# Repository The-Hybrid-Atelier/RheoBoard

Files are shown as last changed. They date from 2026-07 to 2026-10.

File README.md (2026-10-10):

# RheoBoard

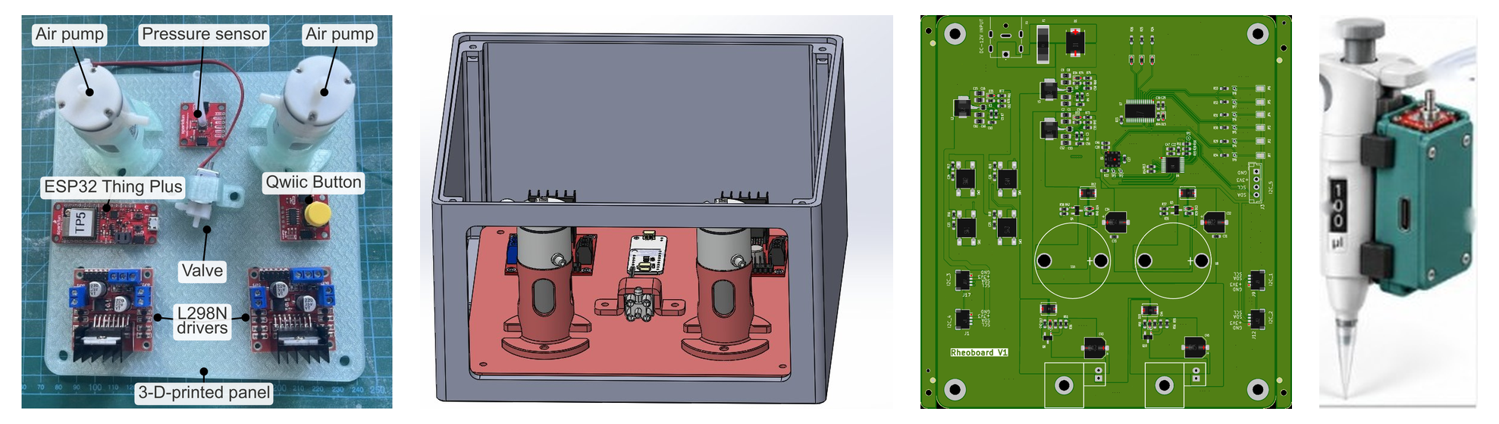
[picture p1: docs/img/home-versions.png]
RheoBoard


RheoBoard is open hardware for pneumatic retraction-extrusion measurements. On command, it runs a REP (retraction-extrusion pulse) and streams the pressure trace.

## Start here

[Wiki Page](https://github.com/The-Hybrid-Atelier/RheoBoard/wiki)

## License

All license notices are consolidated in [`LICENSE`](LICENSE):

- Hardware designs: CERN-OHL-W-2.0
- Firmware: MIT
- Documentation: [CC BY-SA 4.0](https://creativecommons.org/licenses/by-sa/4.0/)

<a href="https://certification.oshwa.org/us002865.html">OSHW certification mark US002865</a>

RheoBoard is certified open source hardware by the Open Source Hardware Association,
UID [US002865](https://certification.oshwa.org/us002865.html); details are on the
[Certification](https://github.com/The-Hybrid-Atelier/RheoBoard/wiki/Certification) page.
The current version is version 1. This is the same version certified by OSHWA as [US002865](https://certification.oshwa.org/us002865.html).
Machine-readable project metadata and the current version are in
[`okh-RheoBoard.yml`](okh-RheoBoard.yml).

## Disclaimer

If you build or distribute a derived unit, do not imply that it is manufactured, sold, warranted,
or endorsed by the original designer.

## Author

Created and maintained by [Charlie Vuong](https://charlie-vuong.com) (The Hybrid Atelier at UT Arlington).

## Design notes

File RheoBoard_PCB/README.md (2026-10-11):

# RheoBoard PCB

This folder holds the PCB designs. There are three versions: [`RheoBoard_v0.05-altium`](RheoBoard_v0.05-altium/), [`RheoBoard_v1`](RheoBoard_v1/), and [`RheoBoard_v1.05`](RheoBoard_v1.05/).

[`RheoBoard_v0.05-altium`](RheoBoard_v0.05-altium/) is a KiCad re-import of the Altium design, saved separately from the other two versions.

[`RheoBoard_v1`](RheoBoard_v1/) holds the KiCad schematic and board for that version, plus symbol, footprint, and 3D libraries, Gerbers, drills, and pick-and-place files.

[`RheoBoard_v1.05`](RheoBoard_v1.05/) holds the v1.05 KiCad project, with revision notes, a BOM, assembly notes, manufacturing files, verification records, and an archive of the historical v1 outputs.

## Files in this folder

Open [`RheoBoard_v1/RheoboardV1/RheoBoard_v1.kicad_pro`](RheoBoard_v1/RheoboardV1/RheoBoard_v1.kicad_pro) in KiCad 10.

- Schematic: [`RheoBoard_v1/RheoboardV1/RheoBoard_v1.kicad_sch`](RheoBoard_v1/RheoboardV1/RheoBoard_v1.kicad_sch)
- Board: [`RheoBoard_v1/RheoboardV1/RheoBoard_v1.kicad_pcb`](RheoBoard_v1/RheoboardV1/RheoBoard_v1.kicad_pcb)
- Libraries: [`RheoBoard_v1/Symbol/`](RheoBoard_v1/Symbol/), [`RheoBoard_v1/Footprint/`](RheoBoard_v1/Footprint/), [`RheoBoard_v1/3D/`](RheoBoard_v1/3D/)
- Gerbers: [`RheoBoard_v1/Gerber/`](RheoBoard_v1/Gerber/)
- Drills: [`RheoBoard_v1/Drill/`](RheoBoard_v1/Drill/)
- Pick-and-place: [`RheoBoard_v1/CPL/CPL.csv`](RheoBoard_v1/CPL/CPL.csv)
- Archived v1 assembly workbook: [`RheoBoard_v1.05/Archive_v1_outputs/BOM/BOM_RheoboardV1_JLCSMT.xlsx`](RheoBoard_v1.05/Archive_v1_outputs/BOM/BOM_RheoboardV1_JLCSMT.xlsx)

License: hardware CERN-OHL-W-2.0 — see [`../LICENSE`](../LICENSE).

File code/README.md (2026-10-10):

# Code

Shared firmware and RheoData notes for the DIY build, the PCB, and the portable version. Install and connect steps are on the [Code](https://github.com/The-Hybrid-Atelier/RheoBoard/wiki/Code) wiki page.

The ESP32 sketch is in `firmware/`. RheoData notes are in `software/`.

Firmware is MIT-licensed. The license notice and full text are in [`../LICENSE`](../LICENSE).

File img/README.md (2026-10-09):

# Images

Project photos and reference photos for the parts in the
[parts list](https://github.com/The-Hybrid-Atelier/RheoBoard/blob/main/BuildYourOwn/hardware/README.md).
One folder per part. Component images come from manufacturer/vendor photography, a freely licensed
source, or a file already in this project, and are for builder identification only.

SparkFun and Adafruit images are used here so a builder can recognize the part when it arrives —
not redistributed as marketing material. Those vendor photos stay under their owners' terms. Link
to the product page for authoritative specs.

| File | Part | Source |
|---|---|---|
| `esp32-thing-plus/esp32-thing-plus.jpg` | SparkFun ESP32 Thing Plus (micro-USB), WRL-15663 | Copied from `BuildYourOwn/images/esp32-thing-plus.jpg`. [SparkFun product page](https://www.sparkfun.com/sparkfun-esp32-thing-plus.html) |
| `qwiic-micropressure/qwiic-micropressure.jpg` | SparkFun Qwiic MicroPressure Sensor, SEN-16476 | Copied from `BuildYourOwn/images/qwiic-micropressure.jpg`. [SparkFun product page](https://www.sparkfun.com/sparkfun-qwiic-micropressure-sensor.html) |
| `qwiic-button/qwiic-button.jpg` | SparkFun Qwiic Button, red, BOB-15932 | Copied from `BuildYourOwn/images/qwiic-button.jpg`. [SparkFun product page](https://www.sparkfun.com/sparkfun-qwiic-button.html) |
| `attiny1616-seesaw/attiny1616-seesaw.jpg` | Adafruit ATtiny1616 Breakout with seesaw, STEMMA QT/Qwiic (PID 5690) | Copied from `BuildYourOwn/images/adafruit-attiny1616-seesaw.jpg`. [Adafruit product page](https://www.adafruit.com/product/5690), image via `https://cdn-shop.adafruit.com/970x728/5690-00.jpg` |
| `air-pump-4699/air-pump-4699.jpg` | Adafruit 4699 — Air Pump and Vacuum DC Motor (ZR370-02PM) | Copied from `BuildYourOwn/images/adafruit-4699-air-pump.jpg`. [Adafruit product page](https://www.adafruit.com/product/4699) |
| `air-valve-4663/air-valve-4663.jpg` | Adafruit 4663 — 6V Air Valve (FA0520E) | Copied from `BuildYourOwn/images/adafruit-4663-air-valve.jpg`. [Adafruit product page](https://www.adafruit.com/product/4663) |
| `l298n/l298n.jpg` | Generic L298N dual H-bridge module | Copied from `BuildYourOwn/images/l298n-motor-driver.jpg`. Cropped from [Wikimedia Commons: *Dosmotorsl298n.jpg*](https://commons.wikimedia.org/wiki/File:Dosmotorsl298n.jpg) by Quel.soler, [CC BY-SA 4.0](https://creativecommons.org/licenses/by-sa/4.0/). No single canonical vendor page exists for this generic module, so this is the best-effort stand-in; swap for your exact board's photo if it differs. |
| `silicone-tube-4661/silicone-tube-4661.jpg` | Adafruit 4661 silicone tubing, 3 mm ID, 5 mm OD, 1 m | Downloaded from [https://cdn-shop.adafruit.com/640x480/4661-00.jpg](https://cdn-shop.adafruit.com/640x480/4661-00.jpg), the product image on [https://www.adafruit.com/product/4661](https://www.adafruit.com/product/4661) |
| `battery-prt-26059/battery-prt-26059.jpg` | SparkFun Lithium Ion Battery 1500 mAh, IEC62133 certified (PRT-26059) | Downloaded from [https://www.sparkfun.com/media/catalog/product/cache/f8158826193ba5faa8b862a9bd1eb9e9/P/R/PRT-26059-Lithium-Ion-Battery-Feature.jpg](https://www.sparkfun.com/media/catalog/product/cache/f8158826193ba5faa8b862a9bd1eb9e9/P/R/PRT-26059-Lithium-Ion-Battery-Feature.jpg), the product image on [https://www.sparkfun.com/lithium-ion-battery-1500mah-iec62133-certified.html](https://www.sparkfun.com/lithium-ion-battery-1500mah-iec62133-certified.html) |
| `panel/panel-annotated.pdf` | Annotated photo of the flat 3D-printed panel | Copied from `BuildYourOwn/cad/encloser/panel-annotated.pdf`. Not fetched. |
| `panel/panel-annotated.jpg` | Same annotated panel photo, as a JPEG | Exported from that one-page PDF (embedded photo, 480×510) so the picture can be shown on a page. Not a new photograph. |
| `panel/encloser_pic1.jpg` | CAD view stored beside the panel print files | Copied from `BuildYourOwn/cad/encloser/encloser_pic1.jpg` and resaved as JPEG. That source file is PNG data with a `.jpg` name. Not fetched. |
| `panel/encloser_pic2.jpg` | CAD view stored beside the panel print files | Copied from `BuildYourOwn/cad/encloser/encloser_pic2.jpg` and resaved as JPEG. That source file is PNG data with a `.jpg` name. Not fetched. |
| `panel/encloser_pic3.jpg` | CAD view stored beside the panel print files | Copied from `BuildYourOwn/cad/encloser/encloser_pic3.jpg` and resaved as JPEG. That source file is PNG data with a `.jpg` name. Not fetched. |
| `teaser/teaser.jpg` | Assembled bench prototype used as the project hero image | Copied from `BuildYourOwn/images/teaser.jpg`. User-provided project photo. |

## Notes

- Originals in `BuildYourOwn/images/` and `BuildYourOwn/cad/encloser/` are left in place.
- If a part is substituted, replace the photo here and update the parts list accordingly.
- No photo is stored here for the GL45 bottle, the GL45 two-port cap, or the tube that connects to
  that cap. Those print files are not in the repository, and no project photo of them was on hand.

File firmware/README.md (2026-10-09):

# Firmware

**Entry point:** [`2P1V_Adafruit/2P1V_Adafruit.ino`](2P1V_Adafruit/2P1V_Adafruit.ino) —
this design's 2 pumps, 1 valve bench firmware for **RheoData** (SparkFun ESP32 Thing Plus,
micro-USB, WRL-15663 + 2× L298N + Qwiic MicroPressure + Qwiic Button + Adafruit ATtiny1616
seesaw breakout). The ESP32 commands the seesaw over Qwiic; seesaw pins `0`, `1`, and `5` then
drive the L298N `ENA`/`ENB` inputs through discrete wires instead of native ESP32 GPIO. The sketch
file/BLE device name in code: `2P1V_Adafruit`.

This firmware is shared by the DIY build, the PCB, and the portable version. Sketch sources live
in `2P1V_Adafruit/` so the sketch folder matches the primary `.ino` filename as Arduino requires.
Firmware is MIT-licensed; the license notice and full text are in the repository-root
[`LICENSE`](../LICENSE). RheoData, the app used with this firmware, is noted in
[`../software/README.md`](../software/README.md). Download, pairing, the connected indicator, and
how to start and name a REP stay TODO and will be specified later in that file and in these notes.

## Toolchain

| Item | Value |
|---|---|
| IDE | [Arduino IDE](https://www.arduino.cc/en/software) 2.x |
| Board | **SparkFun ESP32 Thing Plus** (or generic **ESP32 Dev Module** — plain ESP32-WROOM-32D/E, not S2/S3) |
| ESP32 core | Install via Boards Manager: `esp32` by **Espressif Systems** (add URL below) |
| Baud | 115200 |
| Upload port | micro-USB (same port powers the board and flashes firmware) |

**Additional Boards Manager URL** (Arduino IDE → Settings):

```
https://espressif.github.io/arduino-esp32/package_esp32_index.json
```

(Espressif may also publish `https://dl.espressif.com/dl/package_esp32_index.json` — use whichever
your core version documents.)

## Arduino libraries

| Library | Install via | Purpose |
|---|---|---|
| [SparkFun Qwiic Button](https://github.com/sparkfun/SparkFun_Qwiic_Button_Arduino_Library) | Library Manager | External Qwiic button gestures (REP trigger, latched suck/blow) |
| [SparkFun MicroPressure](https://github.com/sparkfun/SparkFun_MicroPressure_Arduino_Library) | Library Manager | MPRLS sensor |
| [Adafruit seesaw Library](https://github.com/adafruit/Adafruit_Seesaw) | Library Manager (search "Adafruit seesaw Library") | Drives the ATtiny1616 seesaw breakout's PWM/GPIO pins (L298N `ENA`/`ENB`) |
| **[ThingPlusBLEOSC](https://github.com/cearto/ThingPlusBLEOSC)** | Manual (below) | BLE + OSC transport — not on Library Manager |
| OSC (by Adrian Freed) | Library Manager | Required by ThingPlusBLEOSC |
| ESP32 BLE Arduino (by Neil Kolban) | Usually bundled with the `esp32` core | Required by ThingPlusBLEOSC |

**Installing ThingPlusBLEOSC manually:**

```bash
cd ~/Documents/Arduino/libraries
git clone https://github.com/cearto/ThingPlusBLEOSC.git
```

Restart the Arduino IDE afterward so it picks up the new library.

## Upload

1. Open `2P1V_Adafruit/2P1V_Adafruit.ino` in Arduino IDE (from this repo, or your sketchbook copy).
2. Select board **SparkFun ESP32 Thing Plus** (or **ESP32 Dev Module**) and the micro-USB port.
3. Upload. Serial Monitor @ 115200 should print `2P1V_Adafruit initialized`.
4. Builder walkthrough: [`../BuildYourOwn/README.md`](../BuildYourOwn/README.md) → Step 03.

After upload, USB may be disconnected. Portable power is in [Power](#power) below.

## Power

Everyday wall power for the DIY build and for the PCB is a 12 V plug. Pump and valve current
does not go through the ESP32 5 V pin.

USB uploads this firmware to the SparkFun ESP32 Thing Plus. After upload, USB may be disconnected.

Portable power is a [SparkFun Lithium Ion Battery 1500 mAh, IEC62133 certified (SKU PRT-26059)](https://www.sparkfun.com/lithium-ion-battery-1500mah-iec62133-certified.html): nominal 3.7 V, 1500 mAh, terminated with a 2-pin JST-PH connector (2 mm pin spacing), with built-in protection, and it plugs into the ESP32 Thing Plus JST battery connector ([schematic](../BuildYourOwn/hardware/references/datasheets/ESP32_Thing_Plus_Schematic.pdf) V_BATT, 4.2 V maximum).

## Connect and use (summary)

- **BLE:** device advertises as `2P1V_Adafruit`; control via RheoData bridge / OSC (`rheo/rep`, etc.).
- **USB serial (bench):** commands `REP`, `STOP`, `PUMP1 <pct>`, `PUMP2 <pct>` when `SERIAL_STREAM`
  is enabled (default).
- **Qwiic button:** 1-click = REP, 2-click = latched vacuum, hold = momentary pressure.

Builder workflow: [Step 05 — Calibrate and use](../BuildYourOwn/README.md#step-05-calibrate-and-use).

## Firmware pin map

The firmware expects these I2C addresses:

- Qwiic Button: `0x6F`
- MicroPressure (MPRLS): `0x18`
- ATtiny1616 seesaw: `0x49`

| Seesaw pin | Signal | Drives | Pin type |
|---|---|---|---|
| `0` | `PUMP1_EN` | L298N #1 `ENA` — vacuum pump | PWM |
| `1` | `PUMP2_EN` | L298N #1 `ENB` — pressure pump | PWM |
| `4` | `VALVE1_EN` | Reserved for L298N #2 `ENA`; physically NC | digital |
| `5` | `VALVE2_EN` | L298N #2 `ENB` — the only valve driven | digital |

These constants are defined in `2P1V_Adafruit/PneumaticSystem.h`. Physical connections and power
rules are maintained in
[`../BuildYourOwn/hardware/electronic-wiring/README.md`](../BuildYourOwn/hardware/electronic-wiring/README.md).

## Control API

| OSC address | Description |
|---|---|
| `rheo/rep` | Trigger one REP. Ignored if a REP is already running. |
| `rheo/rep/triad` | Trigger three REPs, `rheo/rep/interval` ms apart. |
| `rheo/stop` | Abort the current REP and cancel its triad. |
| `rheo/purge` | Push the line clear with the pressure pump, then stop. |
| `rheo/api` | Print supported OSC messages and send each back over BLE. |

### Sampling

| OSC address | Argument | Default | Description |
|---|---|---|---|
| `rheo/sense/rate` | `[<ms>]` | 10 | Pressure-sampling interval, clamped to 10–1000 ms. Omit the value to read it. |

All parameter addresses below accept an optional value. Omit it to read the current setting.

### REP parameters

| OSC address | Argument | Default | Description |
|---|---|---|---|
| `rheo/rep/pull/power` | `[<0–100>]` | 54 | Retract pump drive level (%). |
| `rheo/rep/pull/time` | `[<ms>]` | 315 | Retract pump run duration, clamped to 1–5000 ms. |
| `rheo/rep/push/power` | `[<0–100>]` | 100 | Extrude ramp ceiling (%). |
| `rheo/rep/push/time` | `[<ms>]` | 345 | Extrude pump run duration, clamped to 1–5000 ms. |
| `rheo/rep/push/ramp/start` | `[<0–100>]` | 40 | Extrude drive level at pump-on. |
| `rheo/rep/push/ramp/time` | `[<ms>]` | 300 | Linear ramp duration; `0` disables the ramp. |
| `rheo/rep/baseline/time` | `[<ms>]` | 420 | Ambient-sampling window before retract. |
| `rheo/rep/interval` | `[<ms>]` | 500 | Gap between REPs in a triad. |

The extrude drive ramps from `push/ramp/start` to `push/power` over `push/ramp/time`, then holds
at `push/power` for the remainder of `push/time`.

### Data path

| OSC address | Description |
|---|---|
| `/rheo/sense/air` | Pressure sample in Pa, streamed while recording. |
| `/db/start` | Signals the start of a REP recording. |
| `/db/save` | Signals the end of a REP recording. |

## REP timing

A REP runs `BASELINE → RETRACT → EXTRUDE → RELAX` in a fixed 1500 ms window (`REP_TIME` in
`2P1V_Adafruit/RheoSystem.h`). The relax tail is the time remaining after baseline, valve-settle,
pull, and push.

```text
0 ms        baseline       settle + retract       settle + extrude       1500 ms
|──────── pumps off ───────|──── vacuum ────|──────── pressure ────────|─ relax ─|
```

## Bench serial commands

Available over USB when `SERIAL_STREAM` is enabled:

| Command | Description |
|---|---|
| `REP` | Trigger one REP. |
| `STOP` | Abort a REP or pump test. |
| `PUMP1 <pct>` | Run the vacuum pump continuously and stream pressure samples. |
| `PUMP2 <pct>` | Run the pressure pump continuously and stream pressure samples. |

Serial output uses `#REP_START`, `#REP_END`, `#PH,<ms>,<phase>`, `#S,<ms>,<Pa>`,
`#TEST_START`, and `#TEST_END`.

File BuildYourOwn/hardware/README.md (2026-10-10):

# Hardware

This folder is the RheoBoardOTS - DIY parts and wiring notes. The purchased-parts list is on the [Parts to buy](https://github.com/The-Hybrid-Atelier/RheoBoard/wiki/Parts-to-buy) wiki page, and printed parts are on the Parts to 3D print page. Wiring is on the Assembly instructions page. Pin notes are in `electronic-wiring/`, tube ports are in `tube-wiring/`, and datasheets are in `references/`.

License: CERN-OHL-W-2.0 — see [`../../LICENSE`](../../LICENSE).

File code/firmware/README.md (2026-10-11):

# Firmware

**Entry point:** `2P1V_Adafruit/2P1V_Adafruit.ino`. Arduino requires the sketch folder name to match the `.ino` file. The sketch file and BLE device name are `2P1V_Adafruit`.

This firmware is shared by the DIY build, the PCB, and the portable version. Install steps are on the [Code](https://github.com/The-Hybrid-Atelier/RheoBoard/wiki/Code) wiki page. RheoData notes are in `../software/README.md`. The download, pairing steps, the connected indicator, and how to start and name a REP are not written yet. That gap stays in the software notes.

Firmware is MIT-licensed. The license notice and full text are in [`../../LICENSE`](../../LICENSE).

## Firmware pin map

The firmware expects these I2C addresses:

- Qwiic Button: `0x6F`
- MicroPressure (MPRLS): `0x18`
- ATtiny1616 seesaw: `0x49`

| Seesaw pin | Signal | Drives | Pin type |
|---|---|---|---|
| `0` | `PUMP1_EN` | L298N #1 `ENA` — vacuum pump | PWM |
| `1` | `PUMP2_EN` | L298N #1 `ENB` — pressure pump | PWM |
| `4` | `VALVE1_EN` | Reserved for L298N #2 `ENA`; physically NC | digital |
| `5` | `VALVE2_EN` | L298N #2 `ENB` — the only valve driven | digital |

These constants are defined in `2P1V_Adafruit/PneumaticSystem.h`. Physical connections are in `BuildYourOwn/hardware/electronic-wiring/` and on the Assembly instructions page.

## Control API

| OSC address | Description |
|---|---|
| `rheo/rep` | Trigger one REP. Ignored if a REP is already running. |
| `rheo/rep/triad` | Trigger three REPs, `rheo/rep/interval` ms apart. |
| `rheo/stop` | Abort the current REP and cancel its triad. |
| `rheo/purge` | Push the line clear with the pressure pump, then stop. |
| `rheo/api` | Print supported OSC messages and send each back over BLE. |

### Sampling

| OSC address | Argument | Default | Description |
|---|---|---|---|
| `rheo/sense/rate` | `[<ms>]` | 10 | Pressure-sampling interval, clamped to 10–1000 ms. Omit the value to read it. |

All parameter addresses below accept an optional value. Omit it to read the current setting.

### REP parameters

| OSC address | Argument | Default | Description |
|---|---|---|---|
| `rheo/rep/pull/power` | `[<0–100>]` | 54 | Retract pump drive level (%). |
| `rheo/rep/pull/time` | `[<ms>]` | 315 | Retract pump run duration, clamped to 1–5000 ms. |
| `rheo/rep/push/power` | `[<0–100>]` | 100 | Extrude ramp ceiling (%). |
| `rheo/rep/push/time` | `[<ms>]` | 345 | Extrude pump run duration, clamped to 1–5000 ms. |
| `rheo/rep/push/ramp/start` | `[<0–100>]` | 40 | Extrude drive level at pump-on. |
| `rheo/rep/push/ramp/time` | `[<ms>]` | 300 | Linear ramp duration; `0` disables the ramp. |
| `rheo/rep/baseline/time` | `[<ms>]` | 420 | Ambient-sampling window before retract. |
| `rheo/rep/interval` | `[<ms>]` | 500 | Gap between REPs in a triad. |

The extrude drive ramps from `push/ramp/start` to `push/power` over `push/ramp/time`, then holds
at `push/power` for the remainder of `push/time`.

### Data path

| OSC address | Description |
|---|---|
| `/rheo/sense/air` | Pressure sample in Pa, streamed while recording. |
| `/db/start` | Signals the start of a REP recording. |
| `/db/save` | Signals the end of a REP recording. |

## REP timing

A REP runs `BASELINE → RETRACT → EXTRUDE → RELAX` in a fixed 1200 ms window (`REP_TIME` in
`2P1V_Adafruit/RheoSystem.h`). The relax tail is the time remaining after baseline, valve-settle,
pull, and push.

```text
0 ms        baseline       settle + retract       settle + extrude       1200 ms
|──────── pumps off ───────|──── vacuum ────|──────── pressure ────────|─ relax ─|
```

## Bench serial commands

Available over USB when `SERIAL_STREAM` is enabled:

| Command | Description |
|---|---|
| `REP` | Trigger one REP. |
| `STOP` | Abort a REP or pump test. |
| `PUMP1 <pct>` | Run the vacuum pump continuously and stream pressure samples. |
| `PUMP2 <pct>` | Run the pressure pump continuously and stream pressure samples. |

Serial output uses `#REP_START`, `#REP_END`, `#PH,<ms>,<phase>`, `#S,<ms>,<Pa>`,
`#TEST_START`, and `#TEST_END`.

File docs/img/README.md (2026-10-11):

# Images

Photos and figures for the public pages. Component photos support the [Parts to buy](https://github.com/The-Hybrid-Atelier/RheoBoard/wiki/Parts-to-buy) wiki page, and the source notes for these files are kept with the wiki images. Part folders are `air-pump-4699/`, `air-valve-4663/`, `attiny1616-seesaw/`, `battery-prt-26059/`, `esp32-thing-plus/`, `l298n/`, `power-adapter-alt-1202/`, `qwiic-button/`, `qwiic-micropressure/`, `silicone-tube-4661/`, and `teaser/`. `panel/` and `portable/` hold the panel and portable figures, and `home-versions.png` is the home figure. `rep-sensing-method.jpg` is the sensing-method diagram, `rep-how-a-rep-looks.jpg` is the chart on How a REP looks, `rep-pressure-trace.jpg` is an earlier pressure trace, `rep-bench.jpg` is the bench photo, `rep-sensing-and-bench.jpg` is an older side-by-side pair; the wiki shows the diagram and the bench photo as two pictures, and `rep-phase-schematic.jpg` is the phase schematic. The certification marks in this folder are `oshwa-certification-mark-US002865-wide.svg`, `oshwa-certification-mark-US002865-stacked.svg`, and `oshwa-license-facts.svg`. Vendor photos stay under their owners' terms.

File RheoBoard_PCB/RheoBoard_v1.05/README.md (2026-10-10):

# RheoBoard v1.05

Ordering notes for this revision are on the [BOM](https://github.com/The-Hybrid-Atelier/RheoBoard/wiki/BOM) page. Open `RheoboardV1/RheoBoard_v1.05.kicad_pro`. The main schematic and PCB use that same stem. Other schematics beside them are standalone block references or stubs, not the project hierarchy.

- Revision notes: `REVISION_NOTES.md`
- BOM: `BOM/README.md`
- Assembly and bringup: `ASSEMBLY_AND_BRINGUP.md` (button cable, GPIO map, and PCA register settings)
- Manufacturing files: `Manufacturing/README.md`
- Current review: `Verification/REVIEW_REPORT.md`
- Change evidence: `Verification/PCA_Control_2026-10-10/README.md`
- Filename-cleanup evidence: `Verification/Rename_2026-10-10/validation.json`
- J18-removal evidence: `Verification/Remove_J18_2026-10-09/README.md`
- `Archive_v1_outputs/` holds the historical v1 outputs, including the original assembly workbook `Archive_v1_outputs/BOM/BOM_RheoboardV1_JLCSMT.xlsx`

This remains an untested hardware revision. Supplier placement review and physical electrical, thermal, and mechanical qualification remain open. The maintainer accepted the retained sensor-reset and valve-voltage-margin risks for this prototype; that acceptance is not a measured hardware result or repeated-production approval. The repository DIY sketch is not verified compatible with this actuator interface.

Hardware design licensing follows the repository root LICENSE, CERN-OHL-W-2.0. Documentation is CC BY-SA 4.0.

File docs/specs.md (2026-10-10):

# Specifications

The figures are on the [Specifications](https://github.com/The-Hybrid-Atelier/RheoBoard/wiki/Specifications) wiki page.

## Open gaps

- TODO: overall assembled size.
- TODO: sensor full-scale range and accuracy.
- TODO: assembled mass.
- TODO: parts cost.
- TODO: tube lengths.

License: CC BY-SA 4.0 — see [Certification](https://github.com/The-Hybrid-Atelier/RheoBoard/wiki/Certification).

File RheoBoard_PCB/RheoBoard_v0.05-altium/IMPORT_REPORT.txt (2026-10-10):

RheoBoard Altium re-import — 2026-10-10

Open: RheoBoard_Altium_Reimport.kicad_pro in KiCad 10.
Source: /Users/charlievuong/Downloads/RheoBoard_V1/

CONVERSION RESULT
The new project is saved separately from the previous Altium import and from
RheoBoard_v1 / RheoBoard_v1.05. No circuit redesign, rerouting, rule suppression,
or component substitution was performed. All 37 original design/output files
remain byte-identical (Finder .DS_Store metadata excluded).

KiCad's native importer recovered all three source sheets:
- MAIN -> RheoBoard_Altium_Reimport.kicad_sch: 79 physical symbols + 24 power symbols.
- POWER -> POWER.kicad_sch: 53 physical symbols + 18 power symbols.
- Block diagram -> RheoBoard_V1.kicad_sch: drawing only, no electrical symbols.
The PCB contains 132 footprints and 71 named nets on two copper layers.
The imported footprint library contains 23 footprint files.

The source project and its block-diagram sheet originally share a filename stem.
A staged copy of the Altium project was given a distinct name before import.
This avoids the previous collision, which lost the detailed MAIN sheet on disk.
The Altium schematic and PCB binary files used for import were unchanged copies.
The three top-level sheet entries now reference three different saved files.

The importer reported eight unavailable PNG illustrations linked to the original
designer's Windows Screenshots directory. These are not circuit symbols or PCB
footprints; their appearance was not recovered. See Missing_Illustrations.txt.
A three-page PDF of the converted sheets is in Verification/Imported_Schematics.pdf.

VERIFICATION
All three saved schematics exported successfully through native KiCad tooling.
The MAIN schematic and PCB were also inspected in their native editors.
An independent IPC-2581 comparison against the previous import found the same
outline, component positions and values, 32 padstacks, and all 16 physical layer
feature groups (including copper, pads, net assignments, solder mask and paste).
Generated package identifiers and four representative package definitions differ;
the full XML files are therefore not byte-identical. This comparison does not
prove that every Altium-specific object or design rule is supported by KiCad.

Native saved-board DRC: 718 findings = 72 errors and 646 warnings.
Analysis-only zone-refill DRC: 679 findings = 47 errors and 632 warnings.
The analysis refill did not change the saved PCB.
Both reports include 297 schematic/PCB comparison findings. These include
53 POWER-sheet footprints missing from the checker’s MAIN-only view, automatic
net-name differences, 91 missing-corresponding-pin reports, imported field
differences, and duplicate references. The pin reports need explicit connectivity
reconciliation; they must not all be dismissed as naming differences.
They are not 297 newly introduced copper defects. The flat, multiple-top-level
project must be reconciled before relying on schematic-to-PCB updates.

Per-sheet electrical checks:
- MAIN: 4 errors / 461 warnings.
- POWER: 4 errors / 358 warnings.
- Block diagram: 0 errors / 0 warnings (no electrical components).
These are per-sheet counts, not a combined project ERC clearance. In particular,
per-sheet power-drive errors can reflect the separate converter sheet. Konnect's
project-ownership guard does not support the two secondary flat sheets; direct
native diagnostic reports were collected for them without modifying source.
Symbol-library, grid and footprint-link findings remain in the imported design.

IMPORTANT REMAINING FINDINGS
1. The PCB still has a B.Cu overlap connecting pump 1's switched node (NetD16_1)
   to valve J8's switched node (NetD10_1). This was also confirmed in the supplied
   original Altium September 28 Gerber, so re-importing does not remove it.
2. MAIN confirms U1 pin 11 / LED5 is unconnected. VALE2 contains only R31 pin 1
   and its test point, consistent with the PCB's missing valve-2 controller drive.
3. Copper-edge, annular-ring, clearance and solder-mask findings remain.
   The source also retains three physical symbols/footprints named GND, which
   must be disambiguated before an engineering-change synchronization.

Status: Circuit sheets and PCB recovered; conversion requires cleanup and the
remaining design findings require review. This is NOT a production release or
proof that the supplied Altium circuit is correct. No fabrication package was
regenerated. This Altium revision is distinct from the later native v1 / v1.05
and must not be assumed to be the board currently in JLCPCB production.

Hardware design license: see ../../LICENSE in the repository root.

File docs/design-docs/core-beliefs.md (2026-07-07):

# Core beliefs

Opinionated, mechanical-where-possible rules for keeping this project legible to future
sessions (agent or human). Update this file when a recurring mistake or preference emerges —
that's cheaper than repeating the correction every session.

- **Prose is the diff for hardware.** Binary CAD files don't show intent in `git diff`. Any
  schematic/layout/library change must be described in `docs/PROGRESS.md` and/or the relevant
  exec-plan in enough detail that someone could reconstruct *why* without opening Altium.
- **Every part is traceable.** A component only belongs in the BOM if its datasheet is linked
  (in `docs/references/index.md` or inline in the exec-plan) and its footprint/symbol has been
  checked against that datasheet. No guessing pinouts or package dimensions.
- **Prefer boring, available parts.** Mainstream, well-documented, multi-sourced components
  beat exotic ones unless there's a documented reason (performance, cost, form factor) — write
  that reason down when it applies.
- **Don't silently resolve ambiguity.** If a spec or requirement is unclear, record the open
  question in the relevant exec-plan's decision log rather than picking an interpretation and
  moving on quietly.
- **Small, meaningful commits.** Even without PRs, each commit on `main` should represent one
  coherent change with a message that explains *why*, not just *what*.
- **Docs are updated in the same sitting as the change**, not deferred — `docs/PROGRESS.md`
  and the relevant exec-plan get updated as part of finishing the work, not as separate cleanup.
- **One deliverable at a time.** Don't try to write the whole BOM, the whole tutorial, or a
  whole board revision in one pass. Pick the single next thing (one BOM section, one tutorial
  step, one sprint contract), finish and verify it, then move on — this is the main way large
  hardware/doc efforts stay coherent instead of sprawling into a half-finished mess.
- **Checklists are a floor, not a self-congratulation exercise.** Don't check off, delete, or
  quietly water down a verification item to make something look done. If an item is genuinely
  obsolete, say so explicitly in the exec-plan's decision log — don't just remove it. If an item
  can't be verified without a human physically doing something, it stays unchecked until a
  human reports back (see `AGENTS.md` → "What the agent can and can't verify").

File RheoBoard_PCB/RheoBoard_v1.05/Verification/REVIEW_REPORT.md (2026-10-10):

# RheoBoard v1.05 review — 2026-10-10

**The PCA/button update is saved and independently checked. ERC and saved/refilled DRC report zero findings, unconnected items and schematic-parity findings under the retained rule settings.** Open [RheoBoard_v1.05.kicad_pro](../RheoboardV1/RheoBoard_v1.05.kicad_pro). Supplier placement acceptance and physical qualification remain open.

U7 controls both pumps and valves, and J19 carries the four buttons to separate ESP32 GPIO inputs. This implements the user's selected Altium-style arrangement. U4 and its dedicated support parts are removed. Valves remain steady ON/OFF; no PWM holding-power change is introduced. J19 has no supply pin; R16–R19 use HOST_3V3 from J9 and retain their 100 nF filters. Use the updated [wiring and control instructions](../ASSEMBLY_AND_BRINGUP.md).

## Current verification

| Check | Result |
| --- | --- |
| Independent change audit | 36/36 checks passed; see the source-bound detailed report. |
| ERC / DRC | 0 schematic errors/warnings; 0 saved/refilled PCB findings, unconnected items and parity findings. |
| Connectivity | 160 components/features and 394 schematic pin nodes. Only the specified U4 removal, valve reassignment and button-header/host-pullup changes. |
| Layout | J19 and R16–R19 placed in the former U4 region. Independent comparison records changed tracks/zones; all unrelated retained placements, pads and routes checked. U12's 26 physical pad records preserved. |
| Rules and mechanics | Outline and rule settings retained; no new exclusions or relaxed constraints. |
| BOM and assembly | 142 fitted parts: 135 matched SMT BOM/CPL references and seven manual parts. J19 is fitted manually. |
| Fabrication | Nine Gerber layers, two drill files and job file. ZIP has exactly those twelve native files. Five current PDF drawings. |
| Portability | 132 present 3D links resolve through portable paths; 87 checked original v1/Altium source files remain unchanged. |

Detailed electrical/layout comparisons, native check reports and source hashes are in [PCA control verification](PCA_Control_2026-10-10/README.md) and the release manifest. The previous [input-stage checkpoint](Altium_Features_2026-10-10/README.md) remains historical evidence for Q11/D37/R85. Those parts and the eFuse, converters and Qwiic interface remain in the design.

Seven SMT components were removed and one manual header added, giving six fewer fitted parts than the preceding v1.05. No current cost saving is claimed without a supplier quote including the header and button cable.

Normal output commands remain independent. PCA9685 reset, SLEEP, OE, ALL_LED and frequency changes are shared by pumps and valves. Communication loss intentionally retains the commanded states. The new button cable requires four input GPIOs per button bank and J9 host power. Firmware must be adapted to this interface; the existing DIY sketch is not verified compatible.

The raw native package has a broader mechanical/manual population than the SMT order. Its warnings are retained in the reconciliation report; the delivered BOM/CPL contains exactly the same 135 purchased SMT references. Native coordinate matching does not establish JLCPCB's physical rotation conventions. Obtain a new placement/stencil preview, including the absence of U4 and its removed support parts.

The following electrical notes cover the retained circuits; accepted sensor-reset and valve-voltage risks remain unchanged. No physical board was powered or measured.

## Full-board electrical and layout review

The retained circuit review covers the input fuse, TVS/eFuse, all three bucks, U5 pressure sensor, U7 PWM driver, four MOSFET load stages, switches, address straps and all bus ports. Both copper layers, solder mask, paste and silkscreen were inspected by region. The 109 × 126.4 mm outline is closed. Power/ground paths and local bypass placement were inspected; no gross routing or mask fault was found. This is a geometry review, not thermal, EMC or transient qualification.

U12 retains a short **0.3 mm × 2 mm output power neck**, with another short 0.3 mm input approach. These are candidates for widening and temperature measurement near the current limit, not demonstrated overheating. The nearest buck input-capacitor pads are about 2.32–2.35 mm from their supply pins; U13 bypass placement remains about 2.07/2.22 mm. No exposed switch-node trace openings were found beyond intended component pads. Pump/hose fit and the inherited conservative pump-body/C34 clearance estimate of about 0.22 mm still need physical confirmation.

Fresh netlist calculations give these output setpoints. Ranges include the regulator's full-temperature reference specification and initial resistor tolerance; they exclude resistor temperature drift, ripple and load transients.

| Rail | Nominal | Calculated range | Onboard nominal output capacitance |
| --- | --- | --- | --- |
| U1 pumps | 4.52 V | 4.354–4.691 V | 88.3 µF |
| U2 valves | 6.00 V | **5.775–6.231 V** | 88.3 µF |
| U3 logic/sensors | 3.30 V | 3.205–3.397 V | 64.40 µF |

The three 100 kΩ VIN-to-EN resistors are explicitly permitted by TI; internal EN clamping is described in its datasheet. The eFuse divider gives about 9.36 V turn-on at VIN_RAW. Its 1.65 kΩ setting is approximately 2 A, and the 390 kΩ clamp selection remains below the buck's steady-state input ceiling. These are component specifications and calculations, not measured surge protection. [Buck datasheet](https://www.ti.com/lit/gpn/tps563203), [eFuse datasheet](https://www.ti.com/lit/ds/symlink/tps25947.pdf).

Two nominal 500 mA pumps plus two valves at the specified 276 mA upper current give about 7.83 W of load power. At an illustrative 85% conversion efficiency this is about 0.77 A from 12 V, before logic, accessories and additional input-stage losses. Pump start/stall current is not established by that running-current estimate. The 2 A input protection does not establish a guaranteed total output-current budget. [Pump](https://www.adafruit.com/product/4699), [valve specification](https://cdn-shop.adafruit.com/product-files/4663/4663_C14660_DC_6V.pdf).

## Controller and multiple-board conditions

The user confirmed **SparkFun ESP32 Thing Plus Micro-B WRL-15663**, GPIO23 SDA / GPIO22 SCL, through its [product page](https://www.sparkfun.com/sparkfun-thing-plus-esp32-wroom-micro-b.html). The current page links the same reviewed schematic. The MPR sensor's specified low output is compatible with U13 A; the checked ESP32 satisfies B's stricter input threshold, and B's output-low limit satisfies the ESP32 input requirement. The [interface review](Qwiic_2026-10-09/interface-engineering-review.json) records calculations and primary sources.

Use an external **TCA9548A at 0x71 with exactly one channel enabled** for multiple boards. Supply master 3.3 V, GND and channel SDA/SCL to each J9. Multiple enabled branches would join buffer B sides, which TI prohibits, and cause address collisions. Upstream B-side repeaters and rise-time accelerators are outside the reviewed arrangement.

Keep total selected host-segment pullup current within **3 mA** and selected-branch effective pullups **at least 2.2 kΩ per signal**, including parallel module resistors and tolerances. The branch limit preserves mux ACK low-level margin through its pass resistance. The board's 4.7 kΩ alone satisfies it. Inspect the actual module and measure low levels/rise times with final cables. Start at 100 kHz; maximum buffer rate is 400 kHz. See [assembly and bringup](../ASSEMBLY_AND_BRINGUP.md).

The additional sensor modules are unspecified. Their parallel pullups, addresses, current demand and added capacitance must be included before qualifying the complete system. The 64.40 µF onboard logic-rail total does not grant an unrestricted capacitor budget, and the buck's rating is not a Qwiic cable-current rating.

## Accepted findings and remaining qualification

1. **U5 startup/reset remains unresolved electrically.** RES still connects only U5.9, R22.2 and TP3.1. Honeywell requires a sufficiently fast VDD rise or reset after stable power; the pullup alone does not guarantee it. Earlier prototype-risk acceptance is not measured qualification. See the [existing finding](Recheck_2026-10-09/sensor-startup-finding.json).
2. **Accepted prototype risk — valve-rail voltage margin.** U2's R60 = 270 kΩ / R74 = 30 kΩ divider targets 6.0 V, but specified tolerances permit about 6.231 V before ripple. The exact FA0520E supplier specification lists 5.0–6.0 V operation. Lower the target with tolerance/transient margin (approximately 5.5–5.7 V), or obtain explicit supplier acceptance of the higher voltage. This is a confirmed missing operating margin, not proof the valves will immediately fail. No resistor was changed during review. [Valve specification §3-2](https://cdn-shop.adafruit.com/product-files/4663/4663_C14660_DC_6V.pdf), [calculation](Thorough_2026-10-09/electrical-review.json).
3. Obtain a new JLCPCB placement/stencil preview. Check Q11 pin order, D37 cathode, U12/U13 pin 1, F1, diode cathodes, capacitor polarity and exact substitutions, especially D36. Live availability for every BOM line and final order settings have not been accepted.
4. Test host-only, board-only, both-powered and both power-up orders, leakage/backfeed, bus edges and reconnect behavior. Datasheet powered-off behavior is not a measurement of these boards.
5. Complete rail startup, load-step/PWM, hot-plug, eFuse, temperature, pump/valve and pressure measurements, including narrow power connections and actual accessories. Check the adapter, cables, mechanical fit and hoses. No enclosure, EMC/ESD, thermal simulation or physical testing was performed.

Communication loss intentionally retains commanded outputs while board power stays stable. Pumps remain fixed-direction and intermittent-use. The repository's DIY firmware is not automatically compatible with this PCB.

No board was powered or physically measured during this work. The [JLCPCB v1 top placement](../Archive_v1_outputs/8815214A_Y73_SMT026093063736_top.png) (order 8815214A_Y73 / SMT026093063736) does not validate v1.05. No manufacturing upload or new order was made.

## Evidence and prior checkpoints

- [Current PCA/button change, independent checks and package reconciliation](PCA_Control_2026-10-10/README.md).
- [Earlier input-stage checkpoint](Altium_Features_2026-10-10/README.md).
- [v1 to v1.05 comparison through the 2026-10-09 checkpoint](V1_TO_V105_COMPARISON.md); the later input-stage and PCA/button deltas are recorded above and in the linked current verification.
- Retained [full-board findings](Thorough_2026-10-09/full-independent-review.json), [electrical calculations](Thorough_2026-10-09/electrical-review.json), and [Qwiic interface review](Qwiic_2026-10-09/interface-engineering-review.json).
- Historical [J18 removal](Remove_J18_2026-10-09/README.md) and [filename-only cleanup](Rename_2026-10-10/validation.json) describe earlier sources, hashes and populations.

Inherited ignored ERC categories remain single_global_label, four_way_junction, simulation_model_issue and footprint_filter. The inherited ignored DRC keys are footprint_filters_mismatch, track_not_centered_on_via and tuning_profile_track_geometries; zero findings does not claim those checks ran. No new instance exclusions or severity relaxations were introduced. All six generic aggregate audits completed; their inherited missing-decoupling heuristic on the jack-to-fuse +12V segment was adjudicated against connectivity, because that segment has no IC supply pin. The raw verdict and reasoning remain in the independent report.

Hardware design licensing follows the repository root LICENSE, CERN-OHL-W-2.0. Documentation is CC BY-SA 4.0.

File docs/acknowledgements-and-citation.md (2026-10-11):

# Citation and Acknowledgements

Hoang Vuong and Cesar Torres describe this routine in [RheoMap: Mapping Inks, Gels, Pastes, and Slurries within a Rheological Embedding Space using Retraction-Extrusion Pressure Sensor Vectors](https://doi.org/10.1145/3706598.3713835) (CHI 2025, Yokohama). In that work, each pulse is kept as a sensor vector so materials can be compared, watched as they change, and told apart by concentration. RheoBoard is open hardware for running the pulse and streaming the pressure trace.

Acknowledgements will be added later.

License: CC BY-SA 4.0 — see [Certification](https://github.com/The-Hybrid-Atelier/RheoBoard/wiki/Certification).

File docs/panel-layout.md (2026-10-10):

# Panel layout

Placement is [Step 01 of the assembly instructions](https://github.com/The-Hybrid-Atelier/RheoBoard/wiki/Assembly-instructions#step-01-assemble-the-platform). The folder name stays `BuildYourOwn/cad/encloser/`. The placement photo is `panel-annotated.pdf` in that folder.

Hole positions are not labeled. TODO: which L298N board is the pump driver and which is the valve driver.

License: CC BY-SA 4.0 — see [Certification](https://github.com/The-Hybrid-Atelier/RheoBoard/wiki/Certification).

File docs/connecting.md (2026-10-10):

# Connecting

Connect steps are on the [Code](https://github.com/The-Hybrid-Atelier/RheoBoard/wiki/Code) wiki page. After [Step 04 — Power-on test](https://github.com/The-Hybrid-Atelier/RheoBoard/wiki/Assembly-instructions#step-04-power-on-test), connect RheoData to `2P1V_Adafruit`.

TODO: the download, pairing steps, the connected indicator, and how to start and name a REP ([`../code/software/README.md`](../code/software/README.md)).

License: CC BY-SA 4.0 — see [Certification](https://github.com/The-Hybrid-Atelier/RheoBoard/wiki/Certification).

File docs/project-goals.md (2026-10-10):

# Project goals

From [`README.md`](../README.md):

RheoBoard is open hardware for pneumatic retraction-extrusion measurements. On command, it runs a REP (retraction-extrusion pulse) and streams the pressure trace.

From `okh-RheoBoard.yml` `intended-use`:

Bench research and teaching instrument for characterizing the pneumatic pressure response of soft/viscous samples. Built and operated by makers, students, and researchers comfortable with the Arduino IDE and reading wiring diagrams. Soldering is only needed when headers or actuator leads are not already fitted. Not a medical or safety-critical device.

TODO: project goals that are not already written in `README.md` or in `okh-RheoBoard.yml` `intended-use`.

License: CC BY-SA 4.0 — see [Certification](https://github.com/The-Hybrid-Atelier/RheoBoard/wiki/Certification).

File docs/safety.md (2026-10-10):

# Safety

Hazards for the RheoBoardOTS - DIY panel, RheoBoard_v1 - PCB, and portable power are on the [Safety](https://github.com/The-Hybrid-Atelier/RheoBoard/wiki/Safety) wiki page.

License: CC BY-SA 4.0 — see [Certification](https://github.com/The-Hybrid-Atelier/RheoBoard/wiki/Certification).

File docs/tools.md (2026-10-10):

# Tools

The tools list is on the [Assembly tools](https://github.com/The-Hybrid-Atelier/RheoBoard/wiki/Assembly-tools) wiki page.

License: CC BY-SA 4.0 — see [Certification](https://github.com/The-Hybrid-Atelier/RheoBoard/wiki/Certification).

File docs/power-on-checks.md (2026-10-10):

# Power-on checks

These checks are [Step 04 — Power-on test](https://github.com/The-Hybrid-Atelier/RheoBoard/wiki/Assembly-instructions#step-04-power-on-test) in the
assembly instructions. That step says "Place the unit".

**Next:** [Step 05 — Calibrate and use](https://github.com/The-Hybrid-Atelier/RheoBoard/wiki/Assembly-instructions#step-05-calibrate-and-use).

License: CC BY-SA 4.0 — see [Certification](https://github.com/The-Hybrid-Atelier/RheoBoard/wiki/Certification).

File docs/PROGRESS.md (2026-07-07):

# Progress log

Running, dated log of what happened and what's next. This is the primary continuity
mechanism between sessions (see `AGENTS.md`) — write entries assuming the next reader
(agent or human) has zero memory of this session.

Newest entries at the top. One entry per session/sitting.

---

## 2026-07-07 (5)

Re-audited the harness against the three source articles (Anthropic long-running-agent posts,
OpenAI harness engineering post) specifically for gaps, not just structure. Found and fixed:

- **Biggest gap: no equivalent of "verify like a real user."** All three articles rely on the
  agent being able to run the software itself (Playwright, curl) to catch premature "done"
  claims. This agent can't solder, cut, or wire anything — so that failure mode (declaring
  victory too early) was completely unguarded against for physical work. Added a new AGENTS.md
  section, "What the agent can and can't verify," drawing a hard line: agent-executable
  (docs/BOM/tutorial writing) vs human-only (anything physical), with an explicit rule to never
  check off a human-only item without a human having reported back.
- Added a **sign-off block** (verified by / date / notes) to both `BuildYourOwn/VERIFICATION.md`
  and `docs/hardware/pcb/verification-checklist.md`, plus a banner stating every item there is
  human-only.
- Added a **top-level deliverables checklist** to `BuildYourOwn/README.md` (BOM / laser-cut /
  wiring / tutorial steps / physically-built-and-verified) — the adapted version of the
  articles' "feature list" concept, so "is this track actually done" has a concrete answer
  instead of a vibe.
- Added `docs/design-docs/core-beliefs.md` principles: work one deliverable at a time (mirrors
  the "one feature/sprint at a time" lesson), and checklists are a floor, not something to
  quietly water down to make progress look better than it is.
- Added `scripts/check-docs.sh` — a dependency-free script (not CI, just run-by-hand) that
  catches dangling relative markdown links, more than one active exec-plan, and docs/BOM
  changes that forgot to update `docs/PROGRESS.md`. Wired into the AGENTS.md session wrap-up
  checklist. This is the OpenAI post's "enforce mechanically, don't rely on memory" lesson,
  scaled down to something cheap enough for a solo docs-heavy repo.
- Fixed a stale link in `docs/exec-plans/_template.md` left over from the previous session's
  `docs/hardware/build-your-own/` removal (would have been caught by the new script).

**Next:** same as before — start populating `BuildYourOwn/BOM.md` and the first tutorial step.
Run `scripts/check-docs.sh` as part of that work, not just retroactively.

## 2026-07-07 (4)

Cleanup: `docs/hardware/build-your-own/` was redundant with `BuildYourOwn/` itself and got
removed, per the harness principle of stripping load-bearing-less complexity rather than
letting it accumulate.

- `docs/hardware/build-your-own/bom.md` was pure indirection (a pointer + notes about
  `BuildYourOwn/BOM.md`) — merged its notes directly into `BuildYourOwn/BOM.md`.
- `docs/hardware/build-your-own/revision-history.md` duplicated `docs/PROGRESS.md`/git log with
  no added value, since (unlike the PCB track's binary files) `BuildYourOwn/` is plain markdown
  and already diffs natively — deleted, not replaced.
- `docs/hardware/build-your-own/verification-checklist.md` had real unique content but was
  misplaced under `docs/` — moved to `BuildYourOwn/VERIFICATION.md`, living with the hardware
  it checks.
- `docs/hardware/pcb/` is unaffected and still justified: Altium binaries have no meaningful
  diff, so BOM notes + revision history need to live somewhere text-based to be legible at all.
- Updated `docs/hardware/index.md` to explain this asymmetry explicitly, so it doesn't get
  "fixed" back into symmetric-but-redundant structure later.

**Next:** same as before — start populating `BuildYourOwn/BOM.md` and the first tutorial step.

## 2026-07-07 (3)

Fleshed out `BuildYourOwn/` into an Instructables-style tutorial structure, per direction that
the deliverable is a full step-by-step guide (BOM, laser-cut platform files, pictographic
circuit diagrams, assembly video) rather than a single flat assembly doc.

- Added `BuildYourOwn/laser-cut/` — scaffold + conventions for platform design files (vector
  source of truth, DXF for cutting, material/thickness/kerf notes to add once known).
- Updated `BuildYourOwn/wiring/README.md` to recommend pictographic/breadboard-style diagrams
  (e.g. Fritzing) over pure schematics, per explicit request.
- Replaced the flat `BuildYourOwn/ASSEMBLY.md` with `BuildYourOwn/tutorial/`: a
  `README.md` table-of-contents/intro, a `steps/` folder (one subfolder per numbered step, each
  with its own `README.md` + `media/`), and a `_step-template/` to copy when adding a step.
  Decided videos should generally be linked externally (e.g. unlisted YouTube) rather than
  committed to git, to avoid repo bloat — documented in `tutorial/README.md`.
- Updated `BuildYourOwn/README.md`, `AGENTS.md`, and
  `docs/hardware/build-your-own/verification-checklist.md` to match.
- Still all empty/TBD scaffolding — no BOM entries, design files, diagrams, or step content
  written yet.

**Next:** pick the first real step to write (probably "gather materials" or "cut the platform")
once parts/design decisions start landing — likely worth an exec-plan for the first pass at the
whole tutorial rather than trickling steps in ad hoc.

## 2026-07-07 (2)

Learned there are two hardware tracks, not one, and restructured the repo accordingly:

- **Build Your Own (BYO)** — off-the-shelf modules/dev boards, breadboard/perfboard, wiring
  diagrams + BOM + assembly guide instead of CAD. **This is the current focus going forward.**
- **PCB** — the existing Altium project (`RheoBoard_V8_Final/`). Not actively worked on now.

Changes:
- Added `BuildYourOwn/` at repo root (`README.md`, `BOM.md`, `ASSEMBLY.md`, `wiring/`) — all
  empty/TBD scaffolding, nothing built yet.
- Split `docs/hardware/` into `docs/hardware/pcb/` (moved the existing BOM-tracking,
  revision-history, verification-checklist docs here unchanged) and
  `docs/hardware/build-your-own/` (new equivalents, adapted for a no-CAD DIY build — e.g. no
  DRC/ERC, continuity/power-up checks instead). Added `docs/hardware/index.md` as the map
  between the two.
- Updated `AGENTS.md`, `README.md`, `docs/product-specs/index.md` to describe both tracks and
  flag BYO as current focus.
- Did **not** touch `RheoBoard_V8_Final/` itself — left it exactly where it is to avoid any
  risk of breaking internal Altium project references.

**Next:** start populating `BuildYourOwn/BOM.md` once parts are chosen — probably worth opening
an exec-plan for the first BYO revision rather than editing ad hoc.

## 2026-07-07

Set up harness engineering scaffolding for solo, direct-to-`main` development, adapted from
Anthropic's long-running agent harness posts and OpenAI's "Harness engineering" post.

- Added `AGENTS.md` (repo map), `README.md`, `.gitignore`/`.gitattributes` tuned for Altium.
- Added `docs/` structure: `design-docs/`, `exec-plans/` (active/completed/tracker/template),
  `product-specs/`, `references/`, `hardware/` (BOM tracking, revision history, verification
  checklist).
- No hardware/product content authored yet — this session was scaffolding only. Repo still
  only contains `RheoBoard_V8_Final/` (Altium project, imported as-is, no revision history
  captured prior to this point).

**Next:** fill in `docs/product-specs/index.md` with the actual RheoBoard/RheoMap/SlipTopo
context once available, and backfill `docs/hardware/revision-history.md` for the existing
V8 board if worth reconstructing.

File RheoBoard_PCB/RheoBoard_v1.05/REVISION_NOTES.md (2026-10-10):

# RheoBoard v1.05 revision record

CAD revision saved and fabrication/assembly exports reconciled on 2026-10-10. Supplier placement acceptance and physical qualification remain open. See the [review report](Verification/REVIEW_REPORT.md).

The maintainer accepted the retained U5 startup/reset and valve-rail voltage-margin risks for this prototype on 2026-10-09. Those circuits are unchanged; their acceptance does not establish measured qualification.

Hardware design licensing follows the repository root LICENSE, CERN-OHL-W-2.0. Documentation is CC BY-SA 4.0.

## Scope and operating decisions

This revision updates the cloned v1.05 project. The previously submitted v1 design remains preserved. The original assembly workbook is [BOM_RheoboardV1_JLCSMT.xlsx](Archive_v1_outputs/BOM/BOM_RheoboardV1_JLCSMT.xlsx). The [JLCPCB corrected top placement](Archive_v1_outputs/8815214A_Y73_SMT026093063736_top.png) is evidence for order 8815214A_Y73 / SMT026093063736 only.

The owner chose to retain the last commanded pump and valve states when master communication stops, retain the current pumps for intermittent use, and operate multiple boards. The working system arrangement uses one board per channel of an external TCA9548A multiplexer. No communication watchdog or reversible motor driver is added. The board continues to generate its own 3.3 V, approximately 4.52 V and 6.0 V rails from 12 V.

## Change register

| Area | v1.05 change | Reason / validation target |
| --- | --- | --- |
| Pump and valve bulk capacitors | C32, C34, C43 and C45 become Panasonic EEEFK1H220P, 22 µF / 50 V, C128458. | Reduces each rail from about 244 µF to 88.3 µF nominal. Verify startup and load transients on hardware. |
| Input protection | Add U12 TPS259472ARPWR, D36 and R78–R81 / C64–C67 downstream of the reverse-polarity stage and ahead of the converters. | Controlled startup, approximately 2 A current limit and 13.8 V nominal clamp. Explicitly approved by the owner. |
| Input fuse | F1 uses a centered project-local JDT JFC1032TS footprint. | Match the selected JFC1032-1200TS fuse and eliminate the old placement-origin offset. |
| Inductors | L1, L2 and L5 use the FXL0530 footprint. | Match C177246 / FXL0530-4R7-M instead of the old Bourns purchasing link and undersized land pattern. |
| Reverse-polarity stage and diodes | Q11/D37/R85 replace D1 with a 60 V P-MOS stage. D11, D12, D16 and D18 retain Jingdao SS34 / SMA. | Reduce series input loss while retaining the fuse and eFuse; verify polarity, transient behavior and temperature. |
| Qwiic master connection | Make J9 the dedicated four-wire Qwiic MASTER port. Add U13 TCA9517ADGKR, C68/C69 and R82–R84; keep J1/J12/J17 as locally powered Qwiic SENSOR ports. | Preserve standard Qwiic cables while separating the USB/battery-powered ESP32 supply from RheoBoard's regulator. Local bus is on U13 A; master is on B. |
| Local debug connection | Retain the existing J3 four-pin JST EH header. Remove the redundant J18 three-pin service header, its schematic stubs, two dedicated PCB branches and service labels. | J3 already exposes GND, onboard 3.3 V, SDA and SCL. J9 remains the intended Qwiic master/mux connection. |
| Actuator controller and buttons | Remove U4 and its dedicated support parts; route valves to U7 LED5/6. Add J19 GPIO header and move R16–R19 beside it, powered by HOST_3V3. | Reduce fitted count by six while retaining four buttons on a separate ESP32 cable. Keep valves FULL ON/OFF and existing pump PWM. |
| Valve connectors | U9 and U10 identify JST B2B-XH-A headers with 2.50 mm pitch. External valves are separate accessories. | Correct the footprint pitch/drill and include the missing fitted headers in the BOM. |
| Probe pads | TP2–TP9 use project-local 1.00 mm copper / 0.50 mm drill footprints. | Increase radial copper ring from 0.175 mm to 0.25 mm; verified in both copper Gerbers and drill exports. |
| Schematic definitions | Correct TPS GND pin types, power flags, unused outputs, component values and project-local library links. | Resolve electrical-rule errors and make the selected parts reproducible. |
| Schematic grid and symbol cleanup | Align connected blocks to the 1.27 mm connection grid, normalize the local PCA9685 symbol, and replace the two inherited pump symbol instances with consistent project-local definitions. | Resolve all 757 grid and two library-cache warnings while preserving the netlist. Update the two pump-to-PCB identity links and retain their assembly exclusions. |
| Schematic presentation | Correct the driver, switch and pressure-sensor captions; clarify the PCA9685 address annotation and component labels. | Make the saved schematic and PDF easier to read without changing the circuit. |
| Assembly metadata | Separate SMT parts from manually fitted headers, jack and pumps. | Keep manual parts out of the SMT placement file and make purchasing quantities explicit. |
| Manufacturing outputs | Generate a fresh BOM, placement file, Gerbers and Excellon drill files after routing checks. | Prevent the copied v1 outputs from being mistaken for v1.05. |

## Selective Altium features — 2026-10-10

The lower-loss input stage replaces D1 with Q11 DMP6023LE-13 (60 V P-channel MOSFET, SOT-223), D37 BZT52C10-7-F (nominal 10 V gate-source zener) and R85 10 kΩ. Q11 pin 2 and its tab are the drain at the fused input; pin 3 is the source at VIN_RAW. Pin 1 is the gate, pulled to GND by R85. D37's cathode connects to the source and its anode to the gate. F1, the downstream U12 eFuse, D36 TVS, converter values, Qwiic interface and mechanical outline are retained.

The selected manufacturer parts are Q11 C154901, D37 C155227 and R85 C25804. Using the MOSFET's maximum 35 mΩ specification at −4.5 V gate drive and 25 °C gives approximately 71 mV drop and 0.144 W conduction loss at the nominal 2.03 A current limit. Resistance increases with temperature. This estimate does not establish the actual board's thermal limit, and the data-sheet headline current rating is not a board current rating. [Diodes DMP6023LE](https://www.diodes.com/datasheet/download/DMP6023LE.pdf).

D37 is nominally 10 V at 5 mA; its current in this circuit is lower, so do not assume exactly −10 V gate drive or use the MOSFET's lower −10 V on-resistance without measurement. Q11 provides reverse-polarity protection but is not a controlled ideal diode: live polarity reversal or removal can briefly conduct backward. U12's downstream reverse-current blocking is retained. Input hot-plug, reversal, startup and temperature remain physical qualification items. [Diodes BZT52C series](https://www.diodes.com/datasheet/download/BZT52Cxx.pdf), [TI TPS25947](https://www.ti.com/lit/ds/symlink/tps25947.pdf).

The later cost-reduction update consolidates actuator control in U7 PCA9685: LED0/1 remain pump PWM, LED2–4 retain their indicators, and LED5/6 now provide steady valve ON/OFF. It removes U4 TCA9534APWR, C22, C47, R10, R11, R13, R14 and its obsolete TP1. The four switches and their 10 kΩ/100 nF networks remain. J19 adds a manually fitted five-pin GPIO header; R16–R19 now use HOST_3V3 from the master Qwiic port. The user explicitly chose a separate button cable to the ESP32, matching Altium's architecture. The exact [wiring and firmware interface](ASSEMBLY_AND_BRINGUP.md#button-gpio-cable) must be used.

Seven SMT parts are removed and one manual header added: 148 → 142 fitted parts, 142 → 135 SMT placements. This reduces component count; actual savings depend on the new assembly quote and the added cable/header. No current price saving is claimed. Valves still use FULL ON/OFF, with no PWM holding-power qualification. All actuators now share the PCA9685's global controls, so firmware must treat resets and frequency changes accordingly. [NXP PCA9685](https://www.nxp.com/docs/en/data-sheet/PCA9685.pdf).

## Input-protection design basis

The input path is J2 → F1 → Q11 drain/tab → Q11 source / VIN_RAW → U12 → protected VIN → the three existing buck converters. D36 is a unidirectional SMBJ13A from VIN_RAW to GND, with its cathode on VIN_RAW. The TVS alone is not the buck overvoltage protection.

U12 uses TI's 10-pad RPW0010A HotRod land pattern. R78/R79 form the 680 kΩ / 100 kΩ undervoltage divider. R80 is 390 kΩ on OVCSEL; R81 is 1.65 kΩ on ILM. C64 is 3.3 nF on DVDT. PG and ITIMER are intentionally unconnected; PGTH is grounded. Local input and output ceramic capacitors must sit next to the corresponding power and ground connections.

C65 is 1 µF / 50 V with C66 = 100 nF on the input. C67 is YAGEO CC1206KKX7R9BB475, 4.7 µF / 50 V / X7R in 1206, directly at the output. Its published typical DC-bias curve retains approximately 2.1 µF at 12 V and 1.8 µF at 14.6 V. A conservative −65% bias allowance combined with −10% initial tolerance and −15% temperature allowance gives approximately 1.26 µF, above TI's local 1 µF recommendation. This uses a typical simulation, not a guaranteed minimum specification. [YAGEO capacitor data](https://www.yageogroup.com/download/specsheet/CC1206KKX7R9BB475).

Calculated nominal settings are approximately 9.36 V turn-on and 8.50 V turn-off at VIN_RAW, 2.03 A current limit, 13.8 V output clamp and 17.7 ms startup at 12 V. Device and component tolerances apply. The input remains a regulated 12 V supply. These settings do not qualify the board for arbitrary adapters, sustained overvoltage or an unspecified surge waveform. [TI TPS25947 datasheet](https://www.ti.com/lit/ds/symlink/tps25947.pdf).

The Littelfuse SMBJ13A procurement code is C151252. The distributor's attribute table conflicts with the named part: require the exact manufacturer part number and the manufacturer's 13 V standoff specification during the assembly review. Do not approve a substitute solely from the distributor's generic attribute table.

## Capacitor calculation

Each of the pump and valve rails has two local 22 µF ceramics, two 22 µF aluminum capacitors and approximately 0.3 µF of small bypass capacitors: 88.3 µF nominal. Applying +20% to the four main capacitors gives approximately 105.9 µF including small bypassing, below the 110 µF recommendation used from TI's design table. That estimate covers positive initial tolerance only; it is not a combined temperature/DC-bias worst case or a measured stability result. More capacitance can affect the converter's compensation and startup, so the 22 µF / 50 V selections are retained. MLCC bias loss, ESR and load behavior still require verification. [TI TPS563203 datasheet](https://www.ti.com/lit/gpn/tps563203), [Panasonic capacitor specification](https://industrial.panasonic.com/ww/products/pt/aluminum-cap-smd/models/EEEFK1H220P).

## Qwiic interface design basis

The intended master is a separately USB/battery-powered ESP32 Thing Plus. All four SH connectors keep Qwiic's pin order: GND, 3.3 V, SDA, SCL. J9 pin 2 feeds HOST_3V3; its SDA/SCL pins feed HOST_SDA/HOST_SCL. These are separate from local +3V3/SDA/SCL. J1, J12 and J17 retain the local nets for sensor expansion. The connector bodies and their board positions are retained. [SparkFun Qwiic](https://www.sparkfun.com/qwiic).

U13's physical pins are 1 VCCA/local +3V3, 2 SCLA/local SCL, 3 SDAA/local SDA, 4 common GND, 5 EN/HOST_3V3, 6 SDAB/HOST_SDA, 7 SCLB/HOST_SCL and 8 VCCB/HOST_3V3. C68/C69 provide 100 nF bypassing. R82/R83 provide host-side 4.7 kΩ pullups, and R84 provides 10 kΩ host-rail discharge. Existing local pullups remain. The IC's powered-off high-impedance behavior prevents a powered host from driving the unpowered local bus through U13; both 3.3 V domains share ground and are not galvanically isolated. [TI TCA9517A, SCPS245E](https://www.ti.com/lit/ds/symlink/tca9517a.pdf).

The local bus must be on A: the MPR sensor's specified low output can be 0.66 V at 3.3 V, above the B-side 0.45 V contention threshold but below A's 0.99 V input threshold. The specified ESP32's maximum 0.33 V low output fits B's input requirement, and B's 0.60 V maximum output low fits the ESP32's 0.825 V input limit. Keep modest pullup loading and verify the actual harness. The checked board is SparkFun WRL-15663 Micro-B, with Qwiic SDA on GPIO23 and SCL on GPIO22. The full source-based interface review is included with the current verification evidence.

Multiple RheoBoards require one channel at a time through a TCA9548A, supplying master 3.3 V to each J9 host interface. Connecting multiple enabled B sides together is prohibited by TI and also causes address collisions. Upstream B-side repeaters and rise-time accelerators are outside the supported arrangement. Keep total selected host-segment pullup current within 3 mA and selected-branch effective pullups at least 2.2 kΩ after parallel combinations and tolerances. The latter preserves the mux ACK low-level margin through its pass-switch resistance; the board's 4.7 kΩ alone is suitable. The [assembly guide](ASSEMBLY_AND_BRINGUP.md) records the wiring, firmware constraints and power-state measurements.

## Prior checkpoint evidence

Before the Qwiic interface addition, saved-board checks reported zero DRC errors, warnings, unconnected items and schematic-parity mismatches. ERC reported zero errors and zero warnings after the grid and library cleanup. All 398 schematic pin nodes were represented on the board. The 141-part fitted BOM and 134-part SMT BOM/CPL pair were reconciled. The eight enlarged probe footprints were applied; all 160 component positions were unchanged from that preceding checkpoint. These counts describe the pre-Qwiic design. The current [review report](Verification/REVIEW_REPORT.md) and release manifest govern the updated files.

The six aggregate audits completed. A generic missing-decoupling finding on the connector-to-fuse +12V segment is adjudicated against the exported connectivity in the review report; the raw result is retained. Three inherited rule keys unavailable in the current KiCad UI remain outside demonstrated rule coverage. The schematic title-block revision remains blank. The warning cleanup did not disable rules or add exclusions; the pre-existing ERC exclusions remain documented in the review report.

Physical acceptance remains open: verify fitted parts and polarity, measure the three rails, startup and load switching, input hot plug, temperature, pump startup, valve behavior, I²C operation through the intended harness, and mechanical fit. Record those results using the assembly and bringup guide before releasing repeated production.

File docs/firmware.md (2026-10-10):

# Firmware

Install steps are on the [Code](https://github.com/The-Hybrid-Atelier/RheoBoard/wiki/Code) wiki page. The sketch is `../code/firmware/2P1V_Adafruit/2P1V_Adafruit.ino`. The pin map, OSC addresses, and serial commands are in `../code/firmware/README.md`. RheoData notes are in `../code/software/README.md`.

License: CC BY-SA 4.0 — see [Certification](https://github.com/The-Hybrid-Atelier/RheoBoard/wiki/Certification).

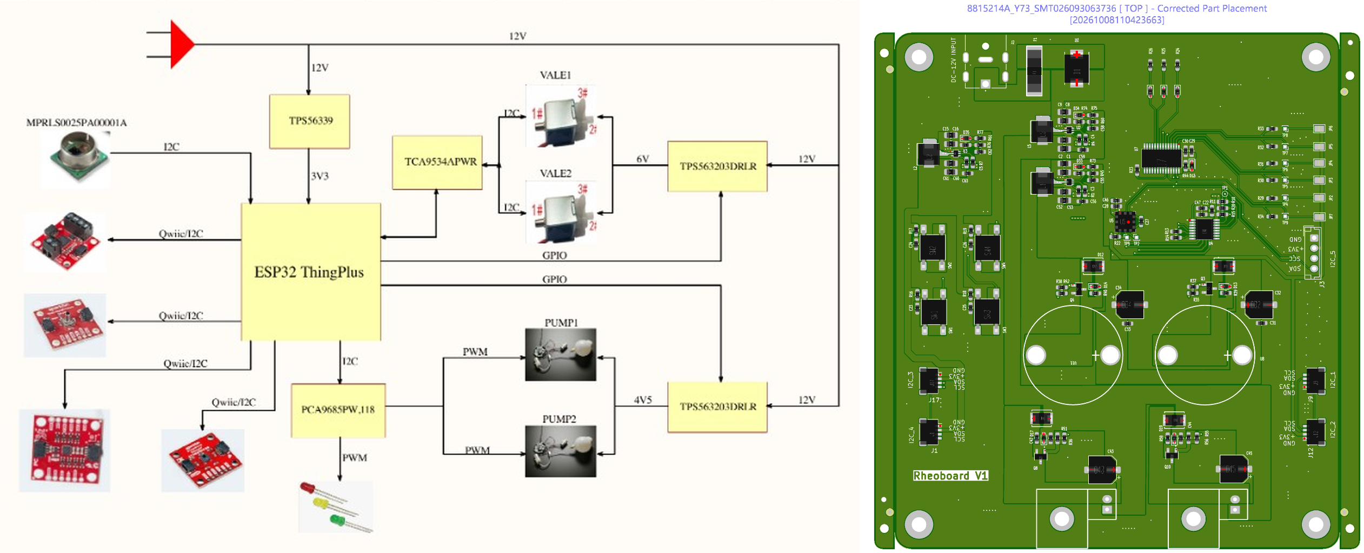
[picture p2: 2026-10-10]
RheoBoard_PCB/images/pcb-schematic-and-v1-board.png

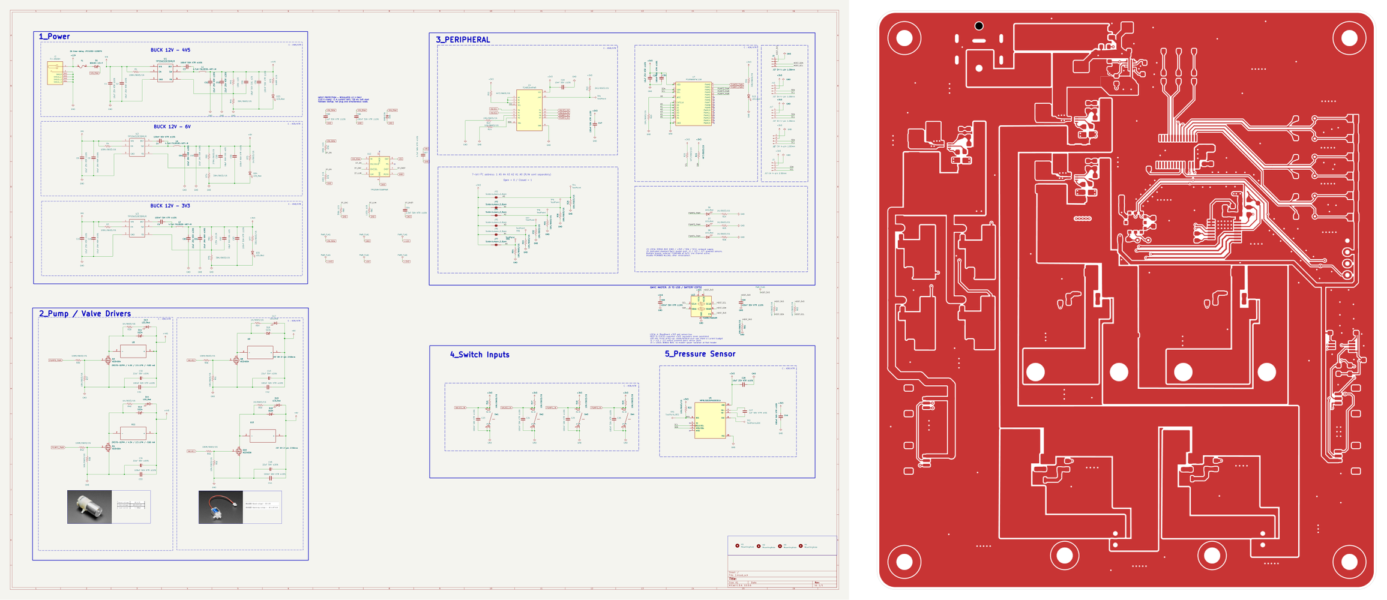
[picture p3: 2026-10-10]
RheoBoard_PCB/images/pcb-v105-schematic-and-board.png

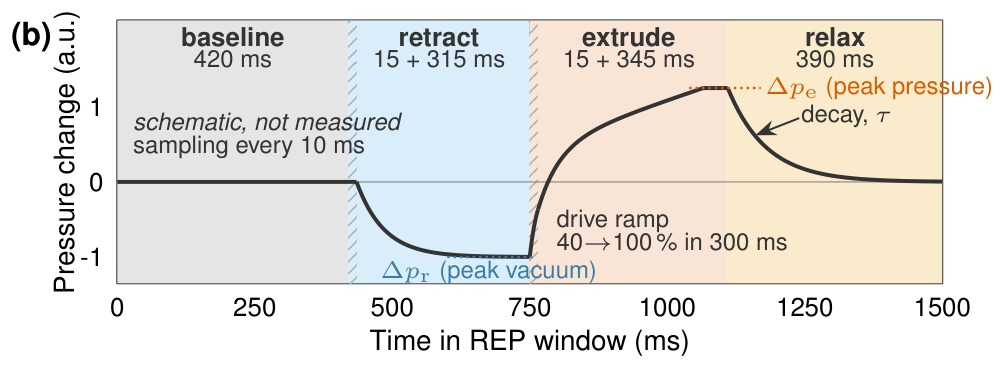
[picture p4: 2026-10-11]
docs/img/rep-phase-schematic.jpg

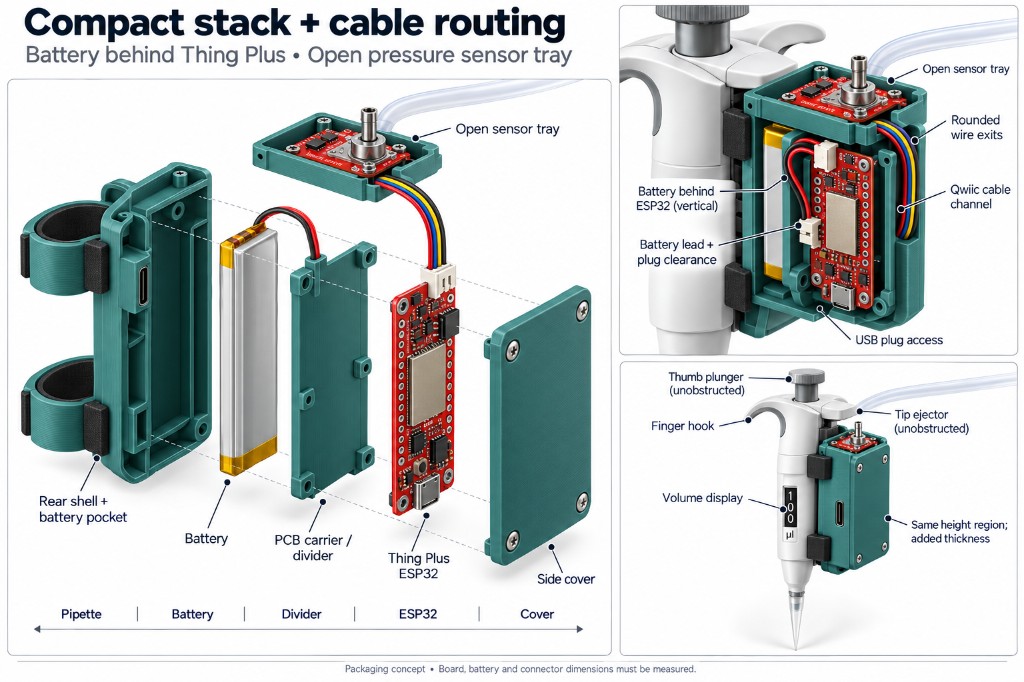
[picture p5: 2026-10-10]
docs/img/portable/portable-concept.jpg

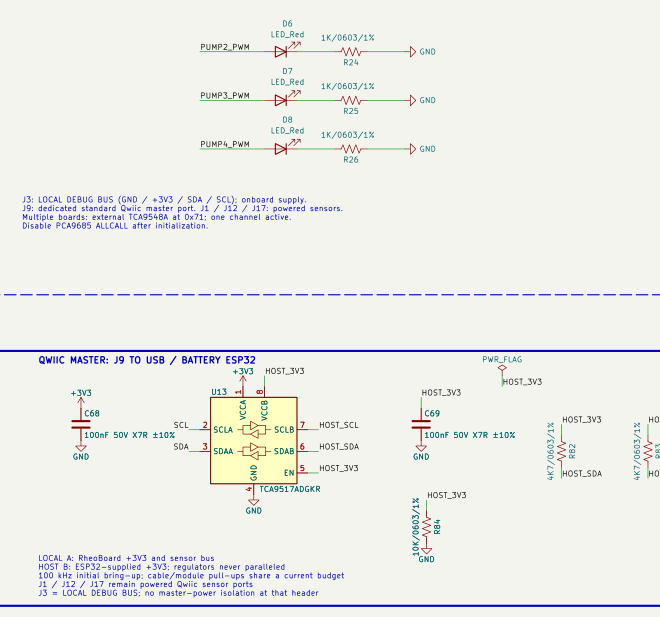
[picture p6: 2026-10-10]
RheoBoard_PCB/RheoBoard_v1.05/Verification/Remove_J18_2026-10-09/schematic-region.png

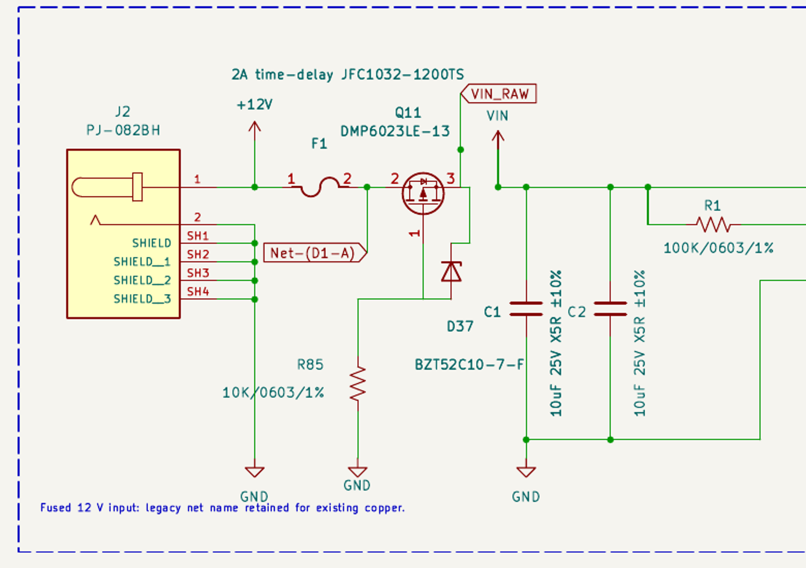
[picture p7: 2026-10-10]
RheoBoard_PCB/RheoBoard_v1.05/Verification/Altium_Features_2026-10-10/final-input-schematic-crop.png

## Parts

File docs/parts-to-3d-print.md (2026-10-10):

# Parts to 3D print

Print files, sizes, and likely roles are on the [Parts to 3D print](https://github.com/The-Hybrid-Atelier/RheoBoard/wiki/Parts-to-3D-print) wiki page. The files are in `BuildYourOwn/cad/encloser/` and `BuildYourOwn/cad/connector/`.

Open gaps:

- TODO: number of copies of each panel part, and of `sensing_tube.stl` and `connector_small.stl`.
- TODO: confirm the role of `part_04.STEP` and `part_05.STEP`. The annotated photo does not label them.
- TODO: print orientation, supports, and any non-default settings per part.
- TODO: material and print settings for the STL files.
- TODO: one GL45 two-port cap, and one tube that connects to that GL45 cap. Those files are not in this repository. `sensing_tube.stl` and `connector_small.stl` are not those parts.

License: CC BY-SA 4.0 — see [Certification](https://github.com/The-Hybrid-Atelier/RheoBoard/wiki/Certification).

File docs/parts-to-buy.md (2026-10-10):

# Parts to buy

The purchased-parts list is on the [Parts to buy](https://github.com/The-Hybrid-Atelier/RheoBoard/wiki/Parts-to-buy) wiki page. Printed parts are on the Parts to 3D print page. Folder notes are in `BuildYourOwn/hardware/`.

License: CC BY-SA 4.0 — see [Certification](https://github.com/The-Hybrid-Atelier/RheoBoard/wiki/Certification).

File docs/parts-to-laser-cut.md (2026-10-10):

# Panel fabrication

RheoBoardOTS - DIY uses the
[3D-printed panel](../BuildYourOwn/cad/encloser/).

License: CC BY-SA 4.0 — see [Certification](https://github.com/The-Hybrid-Atelier/RheoBoard/wiki/Certification).

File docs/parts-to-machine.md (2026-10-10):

# Parts to machine

RheoBoardOTS - DIY has no machined parts. It uses the
[3D-printed panel](../BuildYourOwn/cad/encloser/).

From [`BuildYourOwn/cad/encloser/README.md`](../BuildYourOwn/cad/encloser/README.md): the editable
CAD project that produced the panel STEP exports is not in this repository.

License: CC BY-SA 4.0 — see [Certification](https://github.com/The-Hybrid-Atelier/RheoBoard/wiki/Certification).

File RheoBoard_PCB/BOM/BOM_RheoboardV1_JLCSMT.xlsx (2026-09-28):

Comment | Designator | Footprint | JLCPCB Part #（optional） | Qty | Unit price @ 10 pcs (USD) | Line total (USD) | Link | Backup Link
10uF/25V/0805/1% | C1,C2,C8,C9,C15,C16 | C_0805_2012Metric_Pad1.18x1.45mm_HandSolder | C5448891 | 6 | $0.2560 |  | https://www.mouser.com/ProductDetail/YAGEO/CC0805KKX5R8BB106?qs=57cj7OiSijm89pM64t1AGQ%3D%3D
0.1uF/25V/0603/1% | C3,C4,C5,C23,C24,C25,C26,C30,C31,C33,C42,C44,C46,C47,C56,C59,C63 | C_0603_1608Metric_Pad1.08x0.95mm_HandSolder | C14663 | 17 | $0.0730 |  | https://www.mouser.com/ProductDetail/YAGEO/CC0603KRX7R9BB104?qs=vTakOoo5QyLvVCYM2ge8LQ%3D%3D
10nF/25V/0603/1% | C22 | C_0603_1608Metric_Pad1.08x0.95mm_HandSolder | C57112 | 1 | $0.9200 |  | https://www.mouser.com/ProductDetail/Knowles-Novacap/0603B103K500NT?qs=P%2FxahI%2BVehmDRqlqdBNpcg%3D%3D
1nF/25V/0603/1% | C27 | C_0603_1608Metric_Pad1.08x0.95mm_HandSolder | C5360811 | 1 | $0.0520 |  | https://www.mouser.com/ProductDetail/YAGEO/CC0603KRX7R9BB102?qs=AgBp2OyFlx%2F%2Fw3f5uZqSVQ%3D%3D
10uF/25V/0603/1% | C28,C29 | C_0603_1608Metric_Pad1.08x0.95mm_HandSolder | C7393892 | 2 | $0.1650 |  | https://www.mouser.com/ProductDetail/Murata-Electronics/GRM188R61E106MA73D?qs=PoXZt%2B2CjACpktoD15Kv0Q%3D%3D
100uF/16V | C32,C34,C43,C45 | CP_Elec_6.3x5.4_Nichicon | C128532 | 4 | $0.2830 |  | https://www.mouser.com/ProductDetail/Panasonic-Industry/EEE-FK1C101P?qs=qE6bgDGEOCuSC5c%2BLSbo8Q%3D%3D
22uF/25V/0805/1% | C52,C53,C54,C57,C60,C61 | C_0805_2012Metric_Pad1.18x1.45mm_HandSolder | C20416420 | 6 | $0.2160 |  | https://www.mouser.com/ProductDetail/Murata-Electronics/GRM21BR61E226ME44K?qs=hNud%2FORuBR25jDsUehWlrQ%3D%3D
18pF/25V/0603/1%/C0G/NP0 | C55,C58,C62 | C_0603_1608Metric_Pad1.08x0.95mm_HandSolder | C2169079 | 3 | $0.0430 |  | https://www.mouser.com/ProductDetail/YAGEO/CC0603JRNPO9BN180?qs=vTakOoo5QyKBbsg9i%2BJDzw%3D%3D
B540C | D1 | D_SMC | C72264 | 1 | $0.4380 |  | https://www.mouser.com/ProductDetail/Diodes-Incorporated/B540C-13-F?qs=v2dnQLbuoRZXHN%2FK4ft5%2Bg%3D%3D
LED_Red | D6,D7,D8,D13,D14,D15,D17,D19 | LED_0603_1608Metric_Pad1.05x0.95mm_HandSolder | C434419 | 8 | $0.0980 |  | https://www.mouser.com/ProductDetail/LITEON/LTST-C190KRKT?qs=kAD5fFa1n5VY3YYNWPC1Fg%3D%3D
SS34 | D11,D12,D16,D18 | SS34 | C115205 | 4 | $0.4670 |  | https://www.mouser.com/ProductDetail/onsemi/MBRS340T3G?qs=3JMERSakeboCr3wxBgfY3w%3D%3D
LED_Red | D33,D34,D35 | LED_0603_1608Metric | C434419 | 3 | $0.0980 |  | https://www.mouser.com/ProductDetail/LITEON/LTST-C190KRKT?qs=kAD5fFa1n5VY3YYNWPC1Fg%3D%3D
Qwiic (black) | J1,J9,J12,J17 | JST_SH_SM04B-SRSS-TB_1x04-1MP_P1.00mm_Horizontal | C160404 | 4 | $0.6000 |  | https://www.sparkfun.com/qwiic-jst-connector-smd-4-pin-horizontal.html | https://www.mouser.com/ProductDetail/JST-Commercial/SM04B-SRSS-TBLFSN?qs=cdbOS8ANM9B3FdyA6cNU2A%3D%3D
4.7uH/4A | L1,L2,L5 | 4.7uH_2A | C177246 | 3 | $0.9040 |  | https://www.mouser.com/ProductDetail/Bourns/SRP5030TA-4R7M?qs=ZwKJWZfDtNio1N7LHs0tpQ%3D%3D
AO3400A | Q3,Q4,Q8,Q10 | AO3400A | C20917 | 4 | $0.3220 |  | https://www.digikey.com/en/products/detail/alpha-omega-semiconductor-inc/AO3400A/1856105
100K/0603/1% | R1,R4,R7 | R_0603_1608Metric_Pad0.98x0.95mm_HandSolder | C25803 | 3 | $0.0140 |  | https://www.mouser.com/ProductDetail/YAGEO/RC0603FR-07100KL?qs=e1ok2LiJcmaihem8Va5%2Fsw%3D%3D
2K2/0603/1% | R10 | R_0603_1608Metric_Pad0.98x0.95mm_HandSolder | C4190 | 1 | $0.0140 |  | https://www.mouser.com/ProductDetail/YAGEO/RC0603FR-072K2L?qs=diQw95jMAeOQmNpe2MM%2BPw%3D%3D
4K7/0603/1% | R11,R15,R20 | R_0603_1608Metric_Pad0.98x0.95mm_HandSolder | C23162 | 3 | $0.0010 |  | https://www.mouser.com/ProductDetail/Royalohm/0603WAF4701T5E?qs=e8oIoAS2J1TMXaPvgUFn6Q%3D%3D
10K/0603/1% | R13,R14,R16,R17,R18,R19,R22,R23,R29,R30,R31,R32,R33,R34,R37,R38,R51,R56 | R_0603_1608Metric_Pad0.98x0.95mm_HandSolder | C25804 | 18 | $0.0140 |  | https://www.mouser.com/ProductDetail/YAGEO/RC0603FR-0710KL?qs=grNVn54RoB%2B3GtjbJj3wJQ%3D%3D
1K/0603/1% | R24,R25,R26,R39,R40,R54,R59 | R_0603_1608Metric_Pad0.98x0.95mm_HandSolder | C21190 | 7 | $0.0010 |  | https://www.mouser.com/ProductDetail/Royalohm/0603WAF1001T5E?qs=e8oIoAS2J1QSdiq0gwpEIg%3D%3D
100R/0603/1% | R35,R36,R42,R55 | R_0603_1608Metric_Pad0.98x0.95mm_HandSolder | C22775 | 4 | $0.0140 |  | https://www.mouser.com/ProductDetail/YAGEO/RC0603FR-07100RL?qs=NEN%2FsE%2FLsvPIwIWKCOS4%2FA%3D%3D
330/0603/1% | R44,R77 | R_0603_1608Metric_Pad0.98x0.95mm_HandSolder | C23138 | 2 | $0.0140 |  | https://www.mouser.com/ProductDetail/YAGEO/RC0603FR-07330RL?qs=diQw95jMAeN1335dAOzMfg%3D%3D
197K/0603/1% | R45 | R_0603_1608Metric_Pad0.98x0.95mm_HandSolder | C4203218 | 1 | $0.0200 |  | https://www.mouser.com/ProductDetail/Vishay/CRCW0603196KFKEA?qs=F8Fiu5nZiPgRWYxdubnzvQ%3D%3D
30K/0603/1% | R46,R74,R76 | R_0603_1608Metric_Pad0.98x0.95mm_HandSolder | C22984 | 3 | $0.0140 |  | https://www.mouser.com/ProductDetail/YAGEO/RC0603FR-0730KL?qs=diQw95jMAeNFr44yr782FQ%3D%3D
270K/0603/1% | R60 | R_0603_1608Metric_Pad0.98x0.95mm_HandSolder | C22965 | 1 | $0.0010 |  | https://www.mouser.com/ProductDetail/Royalohm/0603WAF2703T5E?qs=e8oIoAS2J1QsS%2FJYoIXg6Q%3D%3D
135K/0603/1% | R61 | R_0603_1608Metric_Pad0.98x0.95mm_HandSolder | C861113 | 1 | $0.0600 |  | https://www.mouser.com/ProductDetail/YAGEO/RT0603BRD07135KL?qs=JBUVnscnTFIetsNEjxHNJQ%3D%3D
550/0603/1% | R73 | R_0603_1608Metric_Pad0.98x0.95mm_HandSolder | C23079 | 1 | $0.0140 |  | https://www.mouser.com/ProductDetail/YAGEO/RC0603FR-07549RL?qs=gt6vzsuosg3fZB4W1LlPKg%3D%3D
1k/0603/1% | R75 | R_0603_1608Metric_Pad0.98x0.95mm_HandSolder | C21190 | 1 | $0.0010 |  | https://www.mouser.com/ProductDetail/Royalohm/0603WAF1001T5E?qs=e8oIoAS2J1QSdiq0gwpEIg%3D%3D
Button 4 leg | SW1,SW2,SW3,SW4 | SW_Push_1P1T_NO_E-Switch_TL3301NxxxxxG | C273527 | 4 | $0.1830 |  | https://www.mouser.com/ProductDetail/E-Switch/TL3301NF160QG?qs=xDsBkp9LkofW6m%2BYTACJPg%3D%3D
TPS563203DRLR | U1,U2,U3 | TPS563203DRLR | C22445512 | 3 | $0.2250 |  | https://www.mouser.com/ProductDetail/Texas-Instruments/TPS563203DRLR?qs=dbcCsuKDzFXSWrTv7Y7bjQ%3D%3D
TCA9534APWR | U4 | TCA9534APWR | C206010 | 1 | $1.2700 |  | https://www.mouser.com/ProductDetail/Texas-Instruments/TCA9534APWR?qs=asCBFxFfL1RkU8XbvZBOXg%3D%3D
MPRLS0025PA00001A | U5 | MPRLS0025PA00001A | C3257154 | 1 | $15.9300 |  | https://www.mouser.com/ProductDetail/Honeywell/MPRLS0025PA00001A?qs=0lQeLiL1qyYP02EvUZH3dw%3D%3D
PCA9685PW | U7 | PCA9685 | C2678753 | 1 | $3.4450 |  | https://www.digikey.com/en/products/detail/nxp-usa-inc/PCA9685PW-118/5221903 | https://www.mouser.com/ProductDetail/NXP-Semiconductors/PCA9685PW118?qs=6YAT8rHPFU%2BtfwwKq4nwEQ%3D%3D
ZR370-02PM / 4.5V / 2.5 LPM / ~500 mA | U8,U11 | PUMP |  | 2 | $7.1600 |  | https://www.adafruit.com/product/4699
FA0520E / 6V / 3-port / JST XH | U9,U10 | VALVE |  | 2 | $2.6600 |  | https://www.adafruit.com/product/4663
2A | F1 | FUSE | C53035082 | 1 | $1.4500 |  | https://www.mouser.com/ProductDetail/Littelfuse/0461002.ER?qs=bpnLQM2ZShwCPg%2BDpPZgdw%3D%3D
I2C_5 | J3 | Connector_JST:JST_EH_B4B-EH-A_1x04_P2.50mm_Vertical | C160258 | 1 | $0.1390 |  | https://www.digikey.com/en/products/detail/jst-sales-america-inc/B4B-EH-A/758748 | https://www.mouser.com/ProductDetail/JST-Commercial/B4B-EH-ALFSN?qs=cdbOS8ANM9DAINrtzhP3dA%3D%3D
PJ-082BH | J2 | PJ-082BH | C3094233 | 1 | $1.5800 |  | https://www.mouser.com/ProductDetail/Same-Sky/PJ-082BH?qs=WyjlAZoYn52P2Lo8hPB1tg%3D%3D
 |  |  |  | Total

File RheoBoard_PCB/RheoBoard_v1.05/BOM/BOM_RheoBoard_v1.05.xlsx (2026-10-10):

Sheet: Sheet1
Comment | Designator | Footprint | LCSC / JLCPCB part | Qty | Legacy unit estimate (USD) | Priced subtotal (USD) | Selected part source | Datasheet / specification | Manufacturer part number | Manufacturer | Assembly | Revision notes
10uF 25V X5R ±10% | C1, C2, C8, C9, C15, C16 | Capacitor_SMD:C_0805_2012Metric_Pad1.18x1.45mm_HandSolder | C5448891 | 6 | $0.2560 | $1.5360 | https://www.lcsc.com/product-detail/C5448891.html |  | TCC0805X5R106K250FT | CCTC | SMT
100nF 50V X7R ±10% | C3, C4, C5, C23, C24, C25, C26, C30, C31, C33, C42, C44, C46, C56, C59, C63, C68, C69 | Capacitor_SMD:C_0603_1608Metric_Pad1.08x0.95mm_HandSolder | C14663 | 18 | $0.0730 | $1.3140 | https://www.lcsc.com/product-detail/C14663.html |  | CC0603KRX7R9BB104 | YAGEO | SMT | C68/C69 added as local/host U13 supply bypass.
1nF 50V X7R ±5% | C27 | Capacitor_SMD:C_0603_1608Metric_Pad1.08x0.95mm_HandSolder | C5360811 | 1 | $0.0520 | $0.0520 | https://www.lcsc.com/product-detail/C5360811.html |  | TCC0603X7R102J500CT | CCTC | SMT
10uF 25V X5R ±10% | C28, C29 | Capacitor_SMD:C_0603_1608Metric_Pad1.08x0.95mm_HandSolder | C7393892 | 2 | $0.1650 | $0.3300 | https://www.lcsc.com/product-detail/C7393892.html |  | TCC0603X5R106K250CT | CCTC | SMT
22uF 50V ±20% | C32, C34, C43, C45 | Capacitor_SMD:CP_Elec_6.3x5.8 | C128458 | 4 |  |  | https://industrial.panasonic.com/ww/products/pt/aluminum-cap-smd/models/EEEFK1H220P | https://industrial.panasonic.com/cdbs/www-data/pdf/RDE0000/ABA0000C776.pdf | EEEFK1H220P | Panasonic | SMT | Reduced from 100uF to 22uF; each pump/valve rail is approximately 88.3uF nominal. Bench transient validation remains required.
22uF 25V X5R ±20% | C52, C53, C54, C57, C60, C61 | Capacitor_SMD:C_0805_2012Metric_Pad1.18x1.45mm_HandSolder | C20416420 | 6 | $0.2160 | $1.2960 | https://www.lcsc.com/product-detail/C20416420.html |  | TCC0805X5R226M250FT | CCTC | SMT
18pF 50V C0G ±2% | C55, C58, C62 | Capacitor_SMD:C_0603_1608Metric_Pad1.08x0.95mm_HandSolder | C2169079 | 3 | $0.0430 | $0.1290 | https://www.lcsc.com/product-detail/C2169079.html |  | VJ0603A180GXACW1BC | VISHAY | SMT
3.3nF 50V X7R ±10% | C64 | Capacitor_SMD:C_0603_1608Metric | C107088 | 1 |  |  | https://www.lcsc.com/product-detail/C107088.html |  | CC0603KRX7R9BB332 | YAGEO | SMT | New controlled-startup timing capacitor for U12.
1uF 50V X7R ±10% | C65 | Capacitor_SMD:C_0805_2012Metric | C91185 | 1 |  |  | https://www.lcsc.com/product-detail/C91185.html | https://www.yageogroup.com/download/specsheet/CC0805KKX7R9BB105 | CC0805KKX7R9BB105 | YAGEO | SMT | New local input bypass for U12; place beside IN/GND.
100nF 50V X7R ±10% | C66 | Capacitor_SMD:C_0603_1608Metric | C14663 | 1 | $0.0730 | $0.0730 | https://www.lcsc.com/product-detail/C14663.html |  | CC0603KRX7R9BB104 | YAGEO | SMT | New local input high-frequency bypass for U12.
4.7uF 50V X7R ±10% | C67 | Capacitor_SMD:C_1206_3216Metric | C132170 | 1 |  |  | https://www.lcsc.com/product-detail/C132170.html | https://www.yageogroup.com/download/specsheet/CC1206KKX7R9BB475 | CC1206KKX7R9BB475 | YAGEO | SMT | New local output bypass for U12; place beside OUT/GND.
DMP6023LE-13 | Q11 | Package_TO_SOT_SMD:SOT-223-3_TabPin2 | C154901 | 1 |  |  | https://www.lcsc.com/product-detail/C154901.html | https://www.diodes.com/datasheet/download/DMP6023LE.pdf | DMP6023LE-13 | Diodes Incorporated | SMT | Replaces D1 with lower-loss reverse-polarity protection. 1 gate, 2 drain/tab to fused input, 3 source to VIN_RAW.
LED_Red | D6, D7, D8, D13, D14, D15, D17, D19 | LED_SMD:LED_0603_1608Metric_Pad1.05x0.95mm_HandSolder | C434419 | 8 | $0.0980 | $0.7840 | https://www.lcsc.com/product-detail/C434419.html |  | SZYY0603R | Yongyu Photoelectric | SMT
SS34 | D11, D12, D16, D18 | Diode_SMD:D_SMA | C115205 | 4 | $0.4670 | $1.8680 | https://www.lcsc.com/product-detail/C115205.html |  | SS34 | Jingdao Microelectronics | SMT | SMA footprint and polarity mark match selected Jingdao SS34.
LED_Red | D33, D34, D35 | LED_SMD:LED_0603_1608Metric | C434419 | 3 | $0.0980 | $0.2940 | https://www.lcsc.com/product-detail/C434419.html |  | SZYY0603R | Yongyu Photoelectric | SMT
SMBJ13A | D36 | Diode_SMD:D_SMB | C151252 | 1 |  |  | https://www.lcsc.com/product-detail/C151252.html | https://m.littelfuse.com/~/media/electronics/datasheets/tvs_diodes/littelfuse_tvs_diode_smbj_datasheet.pdf.pdf | SMBJ13A | Littelfuse | SMT | Catalog attribute table incorrectly lists 14V/23.2V while selected manufacturer MPN is SMBJ13A. Require exact MPN SMBJ13A, 13V standoff, 21.5V clamp at 28A per manufacturer table; inspect supplier approval. Not a substitute for eFuse.
2A time-delay JFC1032-1200TS | F1 | RheoBoard:Fuse_JDT_JFC1032TS_10.25x3.2mm | C53035082 | 1 | $1.4500 | $1.4500 | https://www.lcsc.com/product-detail/C53035082.html | https://www.jdtfuse.com/upload/PDF/JFC1032TS.pdf | JFC1032-1200TS | JDTfuse | SMT | Corrected centered origin and JDT land pattern. Check the new placement preview.
JST SH 4-pin 1.00mm | J1, J9, J12, J17 | Connector_JST:JST_SH_SM04B-SRSS-TB_1x04-1MP_P1.00mm_Horizontal | C160404 | 4 | $0.6000 | $2.4000 | https://www.lcsc.com/product-detail/C160404.html | https://www.jst-mfg.com/product/pdf/eng/eSH.pdf | SM04B-SRSS-TB(LF)(SN) | JST | SMT | Standard Qwiic pin order: 1 GND, 2 3.3 V, 3 SDA, 4 SCL. J9 is the dedicated MASTER port; J1/J12/J17 power local SENSOR modules. J9 power/signal nets are separated by U13.
PJ-082BH | J2 | RheoBoard:PJ-082BH | C3094233 | 1 | $1.5800 | $1.5800 | https://www.lcsc.com/product-detail/C3094233.html | https://www.sameskydevices.com/product/resource/pj-082bh.pdf | PJ-082BH | CUI | Manual THT | Manual through-hole assembly. Center-positive 12 V, 5.5 x 2.5 mm mating plug.
JST EH 4-pin 2.50mm | J3 | Connector_JST:JST_EH_B4B-EH-A_1x04_P2.50mm_Vertical | C160258 | 1 | $0.1390 | $0.1390 | https://www.lcsc.com/product-detail/C160258.html | https://www.jst-mfg.com/product/pdf/eng/eEH.pdf | B4B-EH-A(LF)(SN) | JST | Manual THT | Manual through-hole assembly. Pin 2 supplies local 3.3 V to peripherals.
4.7uH FXL0530-4R7-M | L1, L2, L5 | Inductor_SMD:L_Changjiang_FXL0530 | C177246 | 3 | $0.9040 | $2.7120 | https://www.lcsc.com/product-detail/C177246.html |  | FXL0530-4R7-M | cjiang | SMT | FXL0530 pads match the selected inductor; old Bourns purchasing link removed.
AO3400A | Q3, Q4, Q8, Q10 | RheoBoard:AO3400A | C20917 | 4 | $0.3220 | $1.2880 | https://www.lcsc.com/product-detail/C20917.html | https://www.aosmd.com/sites/default/files/res/data_sheets/AO3400A.pdf | AO3400A | AOS | SMT
100K/0603/1% | R1, R4, R7 | Resistor_SMD:R_0603_1608Metric_Pad0.98x0.95mm_HandSolder | C25803 | 3 | $0.0140 | $0.0420 | https://www.lcsc.com/product-detail/C25803.html |  | 0603WAF1003T5E | UNI-ROYAL | SMT
4K7/0603/1% | R15, R20, R82, R83 | Resistor_SMD:R_0603_1608Metric_Pad0.98x0.95mm_HandSolder | C23162 | 4 | $0.0010 | $0.0040 | https://www.lcsc.com/product-detail/C23162.html |  | 0603WAF4701T5E | UNI-ROYAL | SMT | R82/R83 added as 4.7 kohm host SDA/SCL pullups; local R15/R20 retained.
10K/0603/1% | R16, R17, R18, R19, R22, R23, R29, R30, R31, R32, R33, R34, R37, R38, R51, R56, R84, R85 | Resistor_SMD:R_0603_1608Metric_Pad0.98x0.95mm_HandSolder | C25804 | 18 | $0.0140 | $0.2520 | https://www.lcsc.com/product-detail/C25804.html |  | 0603WAF1002T5E | UNI-ROYAL | SMT | R16–R19 pull the button signals to HOST_3V3 from J9. R84 discharges HOST_3V3. R85 pulls Q11 gate to GND.
1k/0603/1% | R24, R25, R26, R39, R40, R54, R59, R75 | Resistor_SMD:R_0603_1608Metric_Pad0.98x0.95mm_HandSolder | C21190 | 8 | $0.0010 | $0.0080 | https://www.lcsc.com/product-detail/C21190.html |  | 0603WAF1001T5E | UNI-ROYAL | SMT
100R/0603/1% | R35, R36, R42, R55 | Resistor_SMD:R_0603_1608Metric_Pad0.98x0.95mm_HandSolder | C22775 | 4 | $0.0140 | $0.0560 | https://www.lcsc.com/product-detail/C22775.html |  | 0603WAF1000T5E | UNI-ROYAL | SMT
330/0603/1% | R44, R77 | Resistor_SMD:R_0603_1608Metric_Pad0.98x0.95mm_HandSolder | C23138 | 2 | $0.0140 | $0.0280 | https://www.lcsc.com/product-detail/C23138.html |  | 0603WAF3300T5E | UNI-ROYAL | SMT
196k ±1% | R45 | Resistor_SMD:R_0603_1608Metric_Pad0.98x0.95mm_HandSolder | C4203218 | 1 | $0.0200 | $0.0200 | https://www.lcsc.com/product-detail/C4203218.html |  | CRCW0603196KFKEA | VISHAY | SMT | Schematic corrected to the assembled 196k value; pump rail approximately 4.52 V.
30K/0603/1% | R46, R74, R76 | Resistor_SMD:R_0603_1608Metric_Pad0.98x0.95mm_HandSolder | C22984 | 3 | $0.0140 | $0.0420 | https://www.lcsc.com/product-detail/C22984.html |  | 0603WAF3002T5E | UNI-ROYAL | SMT
270K/0603/1% | R60 | Resistor_SMD:R_0603_1608Metric_Pad0.98x0.95mm_HandSolder | C22965 | 1 | $0.0010 | $0.0010 | https://www.lcsc.com/product-detail/C22965.html |  | 0603WAF2703T5E | UNI-ROYAL | SMT
135k ±0.1% | R61 | Resistor_SMD:R_0603_1608Metric_Pad0.98x0.95mm_HandSolder | C861113 | 1 | $0.0600 | $0.0600 | https://www.lcsc.com/product-detail/C861113.html |  | RT0603BRD07135KL | YAGEO | SMT
549R ±1% | R73 | Resistor_SMD:R_0603_1608Metric_Pad0.98x0.95mm_HandSolder | C23079 | 1 | $0.0140 | $0.0140 | https://www.lcsc.com/product-detail/C23079.html |  | 0603WAF5490T5E | UNI-ROYAL | SMT | Schematic corrected to the assembled 549 ohm value.
680k ±1% | R78 | Resistor_SMD:R_0603_1608Metric | C25822 | 1 |  |  | https://www.lcsc.com/product-detail/C25822.html |  | 0603WAF6803T5E | UNI-ROYAL | SMT
100K/0603/1% | R79 | Resistor_SMD:R_0603_1608Metric | C25803 | 1 | $0.0140 | $0.0140 | https://www.lcsc.com/product-detail/C25803.html |  | 0603WAF1003T5E | UNI-ROYAL | SMT
390k ±1% | R80 | Resistor_SMD:R_0603_1608Metric | C2759410 | 1 |  |  | https://www.lcsc.com/product-detail/C2759410.html |  | HP03W5F3903T5E | UNI-ROYAL | SMT
1.65k ±1% | R81 | Resistor_SMD:R_0603_1608Metric | C22845 | 1 |  |  | https://www.lcsc.com/product-detail/C22845.html |  | 0603WAF1651T5E | UNI-ROYAL | SMT
TL3301NF160QG/P010515 | SW1, SW2, SW3, SW4 | RheoBoard:Tactile_Switch_4pad | C273527 | 4 | $0.1830 | $0.7320 | https://www.lcsc.com/product-detail/C273527.html |  | TL3301NF160QG/P010515 | E-Switch | SMT
TPS563203DRLR | U1, U2, U3 | RheoBoard:TPS563203DRLR | C22445512 | 3 | $0.2250 | $0.6750 | https://www.lcsc.com/product-detail/C22445512.html | https://www.ti.com/lit/gpn/tps563203 | TPS563203DRLR | TI | SMT
MPRLS0025PA00001A | U5 | RheoBoard:MPRLS0025PA00001A | C3257154 | 1 | $15.9300 | $15.9300 | https://www.lcsc.com/product-detail/C3257154.html | https://automation.honeywell.com/content/dam/honeywell-edam/sps/ast/en-us/campaigns/pressure-sensors/documents/sps-siot-mpr-series-datasheet-32332628-ciid-172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 | MPRLS0025PA00001A | Honeywell | SMT
PCA9685PW,118 | U7 | RheoBoard:PCA9685 | C2678753 | 1 | $3.4450 | $3.4450 | https://www.lcsc.com/product-detail/C2678753.html | https://www.nxp.com/docs/en/data-sheet/PCA9685.pdf | PCA9685PW,118 | NXP | SMT | Pumps LED0/1, indicators LED2–4, valves LED5/6 using FULL ON/OFF. TCA9534 removed.
ZR370-02PM / 4.5V / 2.5 LPM / ~500 mA | U8, U11 | RheoBoard:PUMP |  | 2 | $7.1600 | $14.3200 | https://www.adafruit.com/product/4699 |  | ZR370-02PM | Supplier-specified | Manual pump fitting | Existing pump retained for intermittent use. Manual fitting; provide mechanical support.
JST XH 2-pin 2.50mm | U9, U10 | RheoBoard:VALVE_v105 | C158012 | 2 |  |  | https://www.lcsc.com/product-detail/C158012.html | https://www.jst-mfg.com/product/pdf/eng/eXH.pdf | B2B-XH-A(LF)(SN) | JST | Manual THT | Fitted JST XH header only. External valve is listed on Manual accessories. Manual through-hole assembly.
TPS259472ARPWR | U12 | RheoBoard:TI_RPW0010A_VQFN-HR_2x2mm | C3662789 | 1 |  |  | https://www.lcsc.com/product-detail/C3662789.html | https://www.ti.com/lit/ds/symlink/tps25947.pdf | TPS259472ARPWR | Texas Instruments | SMT | New auto-retry input eFuse; TI RPW0010A HotRod footprint, approximately 2 A limit / 13.8 V clamp.
TCA9517ADGKR | U13 | RheoBoard:TI_DGK0008A_VSSOP_3x3mm_P0.65mm | C201698 | 1 |  |  | https://www.lcsc.com/product-detail/C201698.html | https://www.ti.com/lit/ds/symlink/tca9517a.pdf | TCA9517ADGKR | Texas Instruments | SMT | Qwiic master interface: local bus on A, host on B. EN and VCCB use HOST_3V3; separate supplies, common GND. TI DGK land pattern: 1.4 x 0.45 mm pads, 0.65 mm pitch, 4.4 mm row-center span.
BZT52C10-7-F | D37 | Diode_SMD:D_SOD-123 | C155227 | 1 |  |  | https://www.lcsc.com/product-detail/C155227.html | https://www.diodes.com/datasheet/download/BZT52Cxx.pdf | BZT52C10-7-F | Diodes Incorporated | SMT | Q11 gate-source clamp. Cathode to VIN_RAW/source; anode to gate.
Button GPIO 1x05 2.54mm | J19 | Connector_PinHeader_2.54mm:PinHeader_1x05_P2.54mm_Vertical |  | 1 |  |  | https://www.adafruit.com/product/392 |  | 392, cut to 5 positions | Adafruit or equivalent | Manual | Straight 2.54mm male header. Pin1 GND,2 SW1,3 SW2,4 SW3,5 SW4. Buttons need separate GPIO cable and host power through J9.
Total fitted parts / incomplete priced subtotal |  |  |  | 142 | Incomplete estimate | $52.89
Prices are retained from the original workbook only where the selected part is unchanged. New parts have blank prices. This subtotal is incomplete and is not a JLCPCB quotation; obtain a fresh quote for v1.05.

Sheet: Manual accessories
Item | Quantity basis | Manufacturer / supplier | Part number | Purpose | Source | Assembly note
External 6 V valves | 2 per board | Adafruit / supplied manufacturer | FA0520E, product 4663 | Connect to valve headers U9 and U10 | https://www.adafruit.com/product/4663 | Existing specified valve retained. JST XH mating cable; verify supplied cable polarity. Header parts appear on main BOM separately.
Eight-channel I2C multiplexer | 1 per system, up to 8 boards | Adafruit / Texas Instruments | Product 2717 / TCA9548A | One independent RheoBoard per mux channel | https://www.adafruit.com/product/2717 | Address 0x71; exactly one channel enabled. Master 3.3 V/GND/channel SDA/SCL to J9; local rails stay separate. Product 2717 needs a Qwiic adapter harness. No upstream B-side repeater/rise-time accelerator. Total host pullup current <=3 mA; selected-branch effective pullups >=2.2 kohm including parallel module resistors/tolerance. Verify actual wiring and rise times.
12 V power supply | 1 supply per board or budgeted distribution | To be selected | Regulated 12 V, center-positive, 5.5 × 2.5 mm plug | Board input power | https://www.sameskydevices.com/product/resource/pj-082bh.pdf | 12 V, 2 A starting rating for specified loads; validate actual startup and simultaneous-load current. Board input fuse 2 A; do not increase load budget just because supply is larger.
Qwiic master | 1 per system | SparkFun | WRL-15663 (ESP32 Thing Plus, Micro-B) | USB/battery-powered I2C master; GPIO23 SDA, GPIO22 SCL | https://cdn.sparkfun.com/assets/6/d/c/6/c/ESP32_Thing_Plus_Schematic.pdf | Connect four-wire Qwiic to J9 MASTER. Host3V3 powers U13 host interface and R16–R19 button pullups. J19 needs a separate four-GPIO + GND cable. PCB-specific firmware required.
Standard Qwiic cable | 1 per connection | Qwiic-compatible cable supplier | Four-wire JST SH 1.0 mm mating cable; length to suit | Master to J9, or local sensors to J1/J12/J17 | https://www.sparkfun.com/qwiic | Pin 1 GND (black), 2 3.3 V (red), 3 SDA (blue), 4 SCL (yellow). Observe connector pin numbering; do not infer pin order from viewing direction.
Button GPIO cable | 5 leads per board using its buttons | Adafruit or equivalent | 1950: use 5 of 20 female/female 150mm jumpers | J19 buttons to ESP32 GPIO32,33,25,26 and GND | https://www.adafruit.com/product/1950 | J19 pin1 GND;2 GPIO32;3 GPIO33;4 GPIO25(A1);5 GPIO26(A0). Requires male headers on ESP32. Both this cable and Qwiic/J9 are needed; no power wire on J19.

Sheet: JLCPCB SMT only
Comment | Designator | Footprint | LCSC Part #
10uF 25V X5R ±10% | C1, C2, C8, C9, C15, C16 | Capacitor_SMD:C_0805_2012Metric_Pad1.18x1.45mm_HandSolder | C5448891
100nF 50V X7R ±10% | C3, C4, C5, C23, C24, C25, C26, C30, C31, C33, C42, C44, C46, C56, C59, C63, C68, C69 | Capacitor_SMD:C_0603_1608Metric_Pad1.08x0.95mm_HandSolder | C14663
1nF 50V X7R ±5% | C27 | Capacitor_SMD:C_0603_1608Metric_Pad1.08x0.95mm_HandSolder | C5360811
10uF 25V X5R ±10% | C28, C29 | Capacitor_SMD:C_0603_1608Metric_Pad1.08x0.95mm_HandSolder | C7393892
22uF 50V ±20% | C32, C34, C43, C45 | Capacitor_SMD:CP_Elec_6.3x5.8 | C128458
22uF 25V X5R ±20% | C52, C53, C54, C57, C60, C61 | Capacitor_SMD:C_0805_2012Metric_Pad1.18x1.45mm_HandSolder | C20416420
18pF 50V C0G ±2% | C55, C58, C62 | Capacitor_SMD:C_0603_1608Metric_Pad1.08x0.95mm_HandSolder | C2169079
3.3nF 50V X7R ±10% | C64 | Capacitor_SMD:C_0603_1608Metric | C107088
1uF 50V X7R ±10% | C65 | Capacitor_SMD:C_0805_2012Metric | C91185
100nF 50V X7R ±10% | C66 | Capacitor_SMD:C_0603_1608Metric | C14663
4.7uF 50V X7R ±10% | C67 | Capacitor_SMD:C_1206_3216Metric | C132170
DMP6023LE-13 | Q11 | Package_TO_SOT_SMD:SOT-223-3_TabPin2 | C154901
LED_Red | D6, D7, D8, D13, D14, D15, D17, D19 | LED_SMD:LED_0603_1608Metric_Pad1.05x0.95mm_HandSolder | C434419
SS34 | D11, D12, D16, D18 | Diode_SMD:D_SMA | C115205
LED_Red | D33, D34, D35 | LED_SMD:LED_0603_1608Metric | C434419
SMBJ13A | D36 | Diode_SMD:D_SMB | C151252
2A time-delay JFC1032-1200TS | F1 | RheoBoard:Fuse_JDT_JFC1032TS_10.25x3.2mm | C53035082
JST SH 4-pin 1.00mm | J1, J9, J12, J17 | Connector_JST:JST_SH_SM04B-SRSS-TB_1x04-1MP_P1.00mm_Horizontal | C160404
4.7uH FXL0530-4R7-M | L1, L2, L5 | Inductor_SMD:L_Changjiang_FXL0530 | C177246
AO3400A | Q3, Q4, Q8, Q10 | RheoBoard:AO3400A | C20917
100K/0603/1% | R1, R4, R7 | Resistor_SMD:R_0603_1608Metric_Pad0.98x0.95mm_HandSolder | C25803
4K7/0603/1% | R15, R20, R82, R83 | Resistor_SMD:R_0603_1608Metric_Pad0.98x0.95mm_HandSolder | C23162
10K/0603/1% | R16, R17, R18, R19, R22, R23, R29, R30, R31, R32, R33, R34, R37, R38, R51, R56, R84, R85 | Resistor_SMD:R_0603_1608Metric_Pad0.98x0.95mm_HandSolder | C25804
1k/0603/1% | R24, R25, R26, R39, R40, R54, R59, R75 | Resistor_SMD:R_0603_1608Metric_Pad0.98x0.95mm_HandSolder | C21190
100R/0603/1% | R35, R36, R42, R55 | Resistor_SMD:R_0603_1608Metric_Pad0.98x0.95mm_HandSolder | C22775
330/0603/1% | R44, R77 | Resistor_SMD:R_0603_1608Metric_Pad0.98x0.95mm_HandSolder | C23138
196k ±1% | R45 | Resistor_SMD:R_0603_1608Metric_Pad0.98x0.95mm_HandSolder | C4203218
30K/0603/1% | R46, R74, R76 | Resistor_SMD:R_0603_1608Metric_Pad0.98x0.95mm_HandSolder | C22984
270K/0603/1% | R60 | Resistor_SMD:R_0603_1608Metric_Pad0.98x0.95mm_HandSolder | C22965
135k ±0.1% | R61 | Resistor_SMD:R_0603_1608Metric_Pad0.98x0.95mm_HandSolder | C861113
549R ±1% | R73 | Resistor_SMD:R_0603_1608Metric_Pad0.98x0.95mm_HandSolder | C23079
680k ±1% | R78 | Resistor_SMD:R_0603_1608Metric | C25822
100K/0603/1% | R79 | Resistor_SMD:R_0603_1608Metric | C25803
390k ±1% | R80 | Resistor_SMD:R_0603_1608Metric | C2759410
1.65k ±1% | R81 | Resistor_SMD:R_0603_1608Metric | C22845
TL3301NF160QG/P010515 | SW1, SW2, SW3, SW4 | RheoBoard:Tactile_Switch_4pad | C273527
TPS563203DRLR | U1, U2, U3 | RheoBoard:TPS563203DRLR | C22445512
MPRLS0025PA00001A | U5 | RheoBoard:MPRLS0025PA00001A | C3257154
PCA9685PW,118 | U7 | RheoBoard:PCA9685 | C2678753
TPS259472ARPWR | U12 | RheoBoard:TI_RPW0010A_VQFN-HR_2x2mm | C3662789
TCA9517ADGKR | U13 | RheoBoard:TI_DGK0008A_VSSOP_3x3mm_P0.65mm | C201698
BZT52C10-7-F | D37 | Diode_SMD:D_SOD-123 | C155227

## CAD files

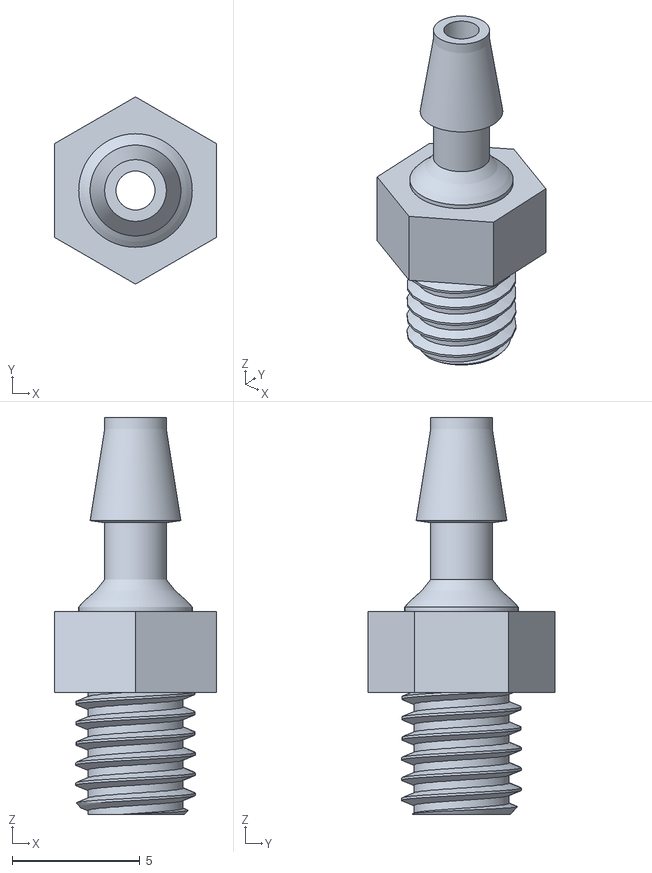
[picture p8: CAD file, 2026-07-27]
BuildYourOwn/cad/connector/connector_small.stl
6.35 x 7.33 x 15.5

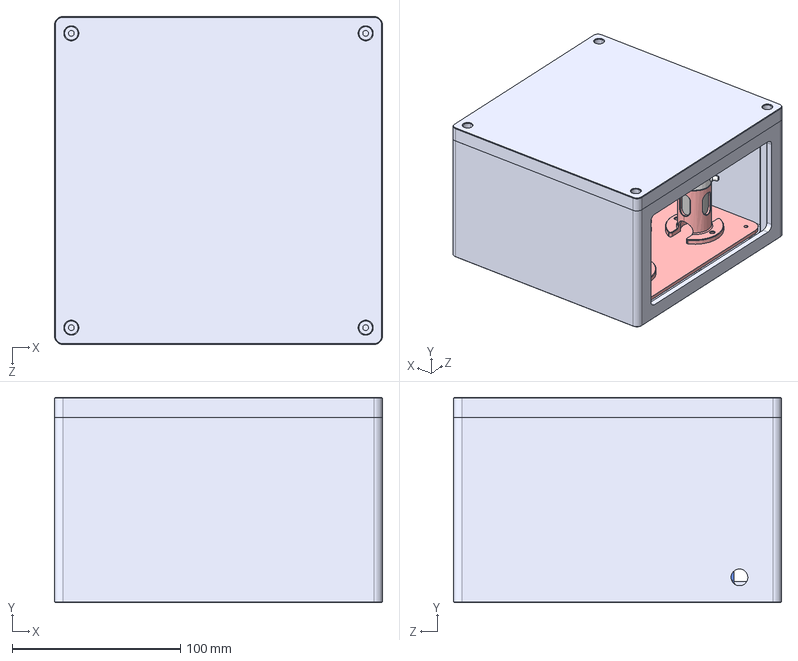
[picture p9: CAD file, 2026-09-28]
BuildYourOwn/cad/encloser/Concept_v2.STEP
195.0 x 122.0 x 195.0 mm
hop dien 01
Vacuum Pump 370A x 2
6V Solenoid Valve
hop dien 02 x 2
Adafruit_ISM330DHXC
L298N Motor Driver x 2
hop dien 03
hop dien 04
hop dien 06

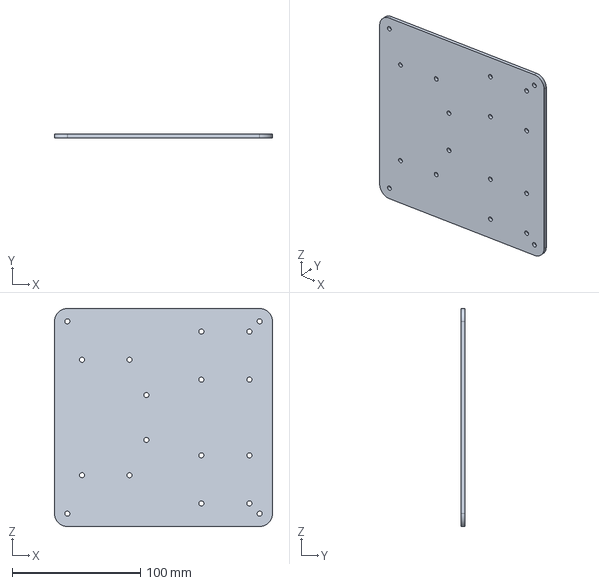
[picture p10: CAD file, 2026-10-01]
BuildYourOwn/cad/encloser/part/part_01_holes_4mm.STEP
170.0 x 3.00 x 170.0 mm

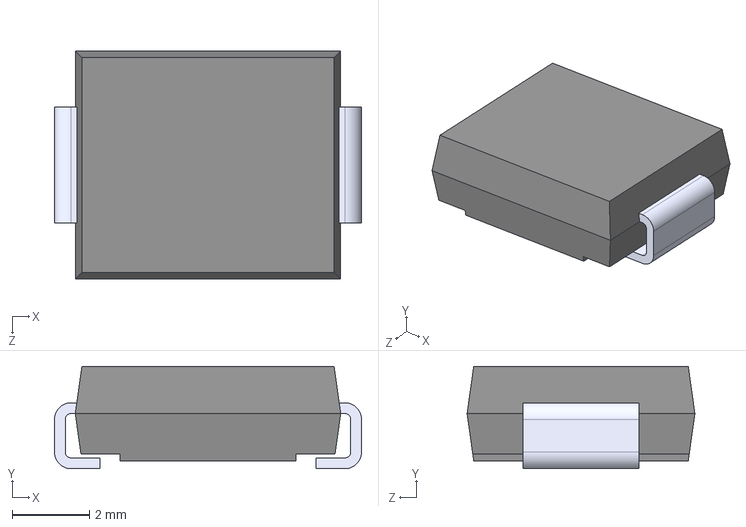
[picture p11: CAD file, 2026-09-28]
RheoBoard_PCB/RheoBoard_v1.05/3D/SS34.STEP
7.95 x 2.65 x 5.90 mm

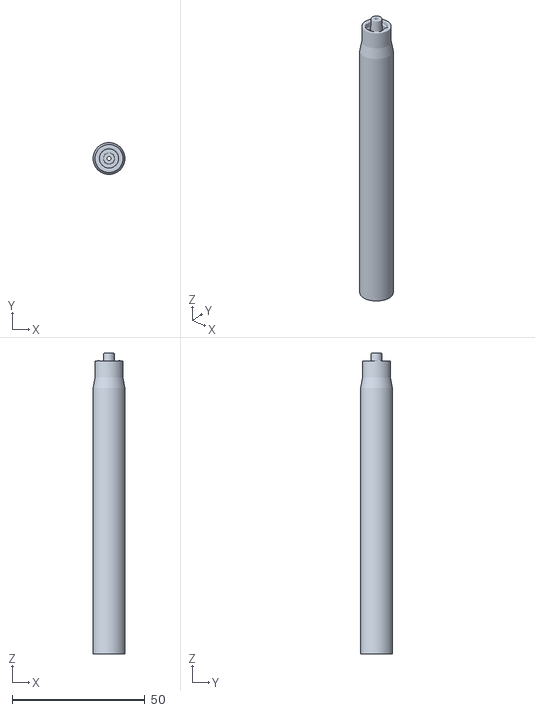
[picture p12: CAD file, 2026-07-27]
BuildYourOwn/cad/connector/sensing_tube.stl
12.0 x 12.0 x 113.2

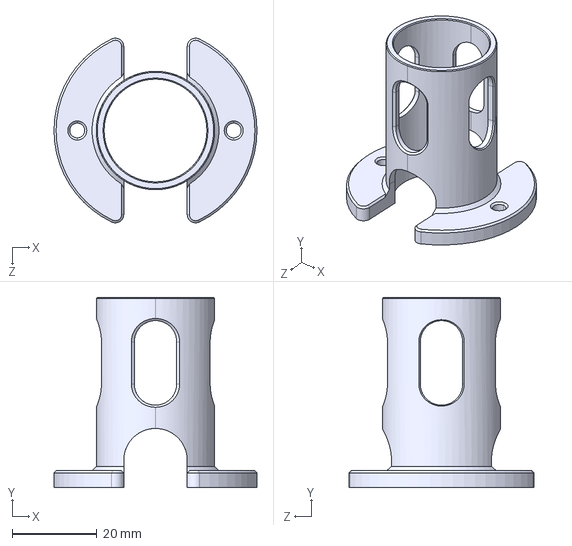
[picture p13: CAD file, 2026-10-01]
BuildYourOwn/cad/encloser/part/part_2.STEP
48.0 x 45.0 x 43.7 mm

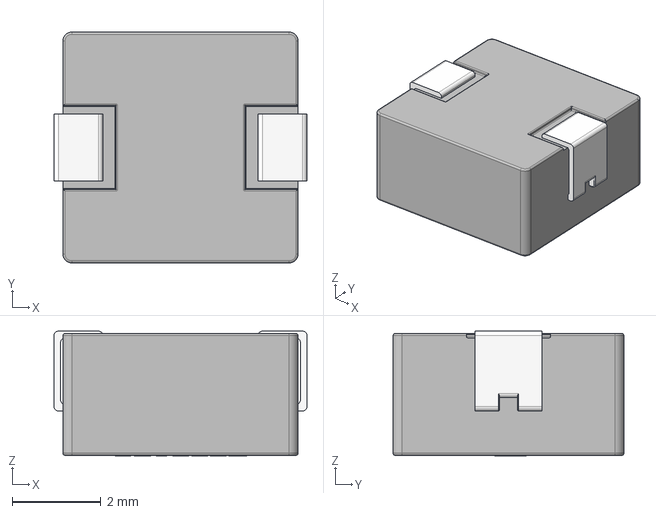
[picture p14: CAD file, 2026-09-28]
RheoBoard_PCB/RheoBoard_v1.05/3D/4.7uH_2A.stp
5.70 x 5.20 x 2.81 mm

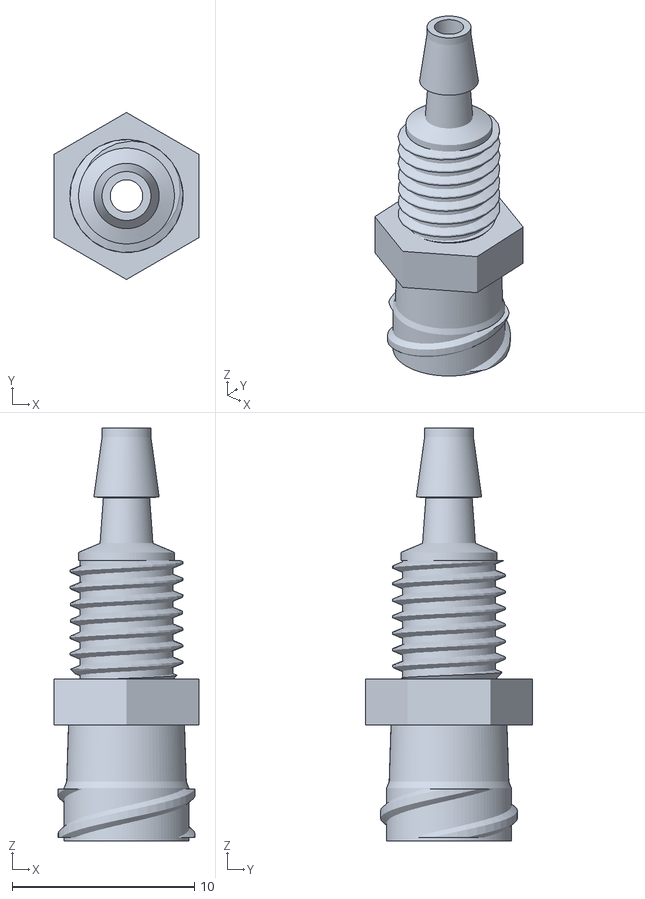
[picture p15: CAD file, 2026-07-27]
BuildYourOwn/cad/connector/connector_big.stl
7.92 x 9.15 x 22.6

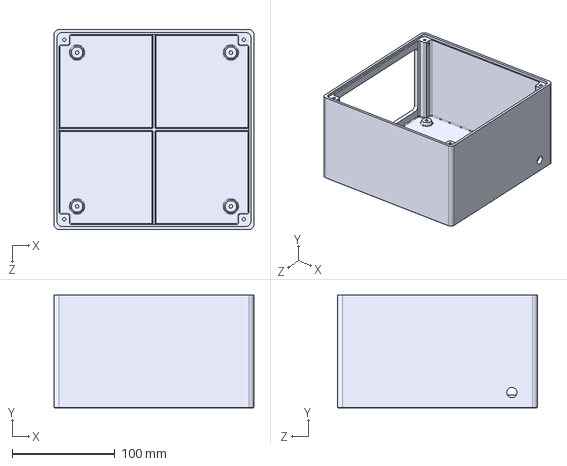
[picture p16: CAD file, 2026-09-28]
BuildYourOwn/cad/encloser/part/part_04.STEP
195.0 x 110.0 x 195.0 mm

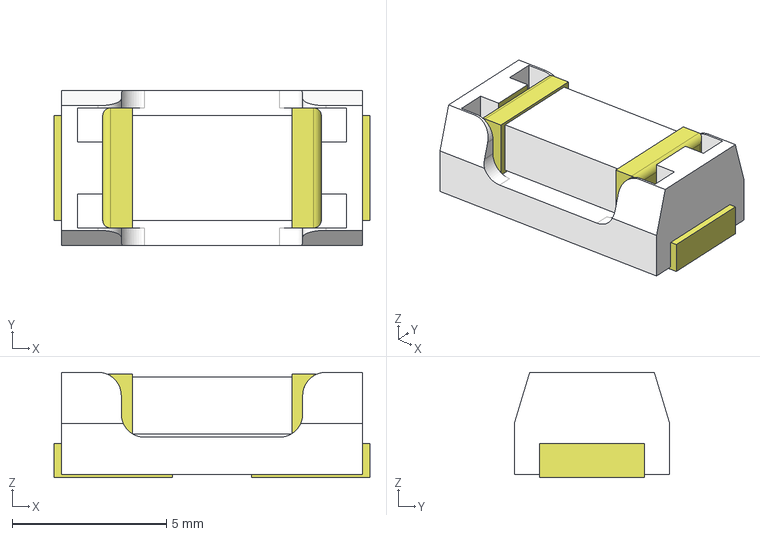
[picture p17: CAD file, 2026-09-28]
RheoBoard_PCB/RheoBoard_v1.05/3D/Fuse .step
10.2 x 5.03 x 3.41 mm
fuse-real
FusePart

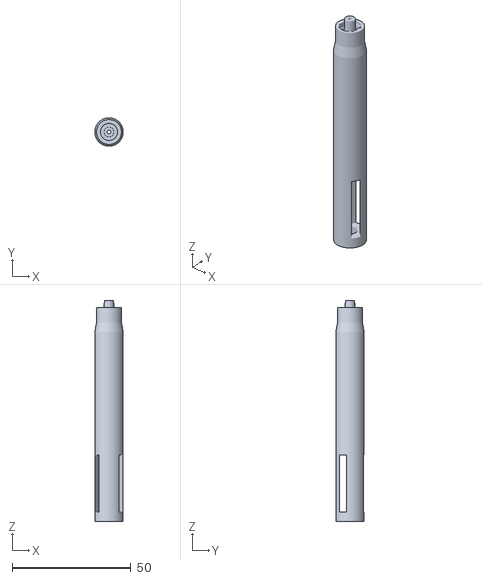
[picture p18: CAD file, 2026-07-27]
BuildYourOwn/cad/connector/sensing_tube_open.stl
12.0 x 12.0 x 93.2

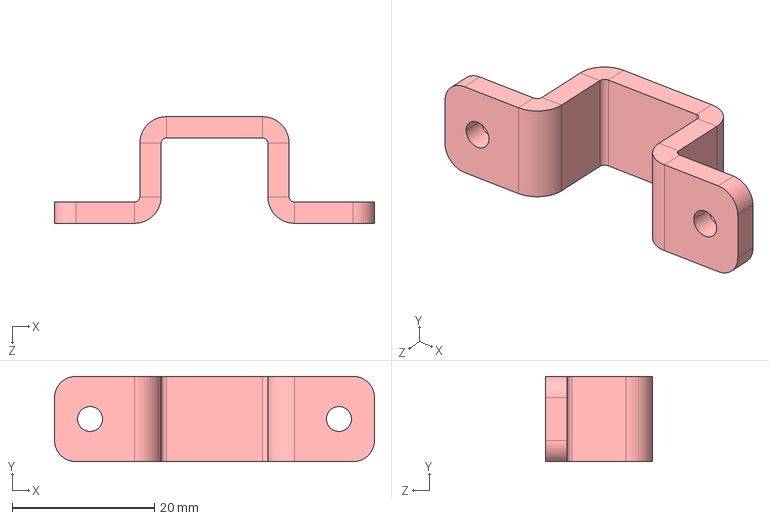
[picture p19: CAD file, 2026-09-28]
BuildYourOwn/cad/encloser/part/part_03.STEP
45.0 x 12.0 x 15.0 mm

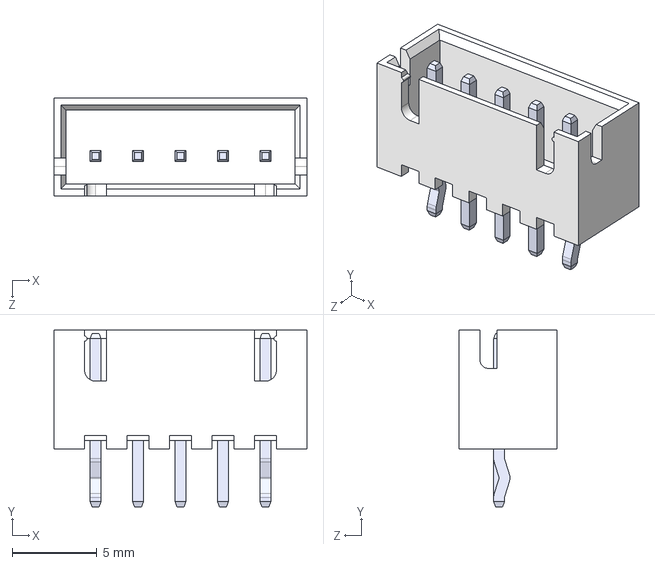
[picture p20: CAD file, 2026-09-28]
RheoBoard_PCB/RheoBoard_v1.05/3D/B5B-XH-A.step
14.9 x 10.4 x 5.75 mm

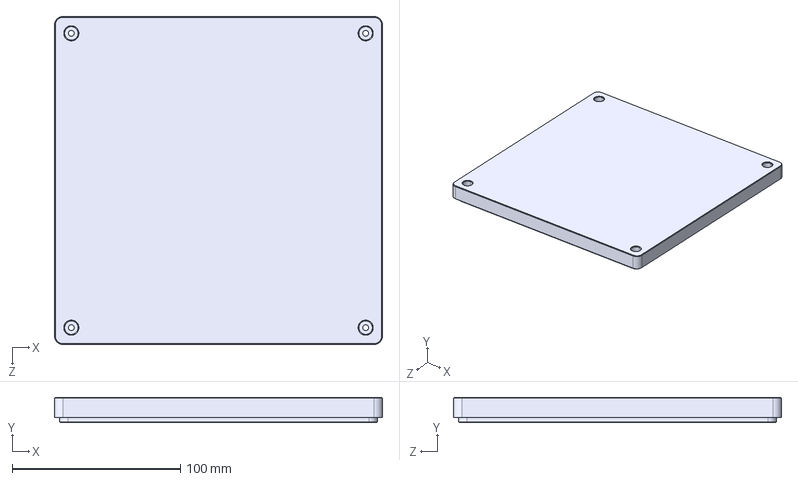
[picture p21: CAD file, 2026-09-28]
BuildYourOwn/cad/encloser/part/part_05.STEP
195.0 x 15.0 x 195.0 mm

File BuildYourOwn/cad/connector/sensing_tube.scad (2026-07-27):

// ============================================================
// HANGING TUBE WITH MALE LUER-LOCK CONNECTOR
//
// Connects to:
// Value Plastics FTLLB220-6005
// Female luer thread panel-mount fitting
//
// Rectangular/triangular side opening removed.
// ============================================================


// -------------------------
// General parameters
// -------------------------

resolution = 120;
$fn = resolution;

outer_radius = 6;
inner_radius = 2.75;

tube_height = 100;


// -------------------------
// Connector transition
// -------------------------

transition_height = 4;


// -------------------------
// Male luer taper
// -------------------------

// Nominal male luer taper is 6%.
luer_length = 8.2;
luer_taper  = 0.06;

// Negative = smaller/looser
// Positive = larger/tighter
luer_size_adjust = 0;

luer_tip_diameter =
    3.94 + luer_size_adjust;

luer_base_diameter =
    luer_tip_diameter +
    luer_taper * luer_length;

luer_bore_diameter = 1.6;


// -------------------------
// Male luer-lock collar
// -------------------------

lock_collar_outer_diameter = 10.5;
lock_collar_height         = 6.2;
lock_base_height           = 1.0;

thread_diametral_clearance = 0.20;

thread_crest_diameter =
    7.0 + thread_diametral_clearance;

thread_root_diameter =
    8.0 + thread_diametral_clearance;

// Double-start right-hand thread
thread_pitch = 2.5;
thread_lead  = thread_pitch * 2;

thread_start_height =
    lock_base_height + 0.20;

thread_height =
    lock_collar_height -
    thread_start_height +
    0.10;

thread_crest_half_width = 0.42;
thread_root_half_width  = 1.20;


// -------------------------
// Test-print option
// -------------------------

test_connector_only = false;


// ============================================================
// INTERNAL HELICAL THREAD RIDGE
// ============================================================

module internal_thread_ridge(start_angle = 0) {

    rotate([0, 0, start_angle])

        linear_extrude(
            height = thread_height,
            twist = -360 * thread_height / thread_lead,
            slices = 150,
            convexity = 12
        )

            polygon(points = [

                [
                    thread_crest_diameter / 2,
                    -thread_crest_half_width
                ],

                [
                    thread_root_diameter / 2 + 0.10,
                    -thread_root_half_width
                ],

                [
                    thread_root_diameter / 2 + 0.10,
                    thread_root_half_width
                ],

                [
                    thread_crest_diameter / 2,
                    thread_crest_half_width
                ]
            ]);
}


// ============================================================
// SOLID MALE LUER-LOCK CONNECTOR
// ============================================================

module male_luer_lock_solid() {

    union() {

        // Bottom plate connecting the collar and luer cone
        cylinder(
            h = lock_base_height,
            d = lock_collar_outer_diameter
        );


        // Hollow locking collar
        translate([0, 0, lock_base_height])

            difference() {

                cylinder(
                    h =
                        lock_collar_height -
                        lock_base_height,
                    d = lock_collar_outer_diameter
                );

                translate([0, 0, -0.1])

                    cylinder(
                        h =
                            lock_collar_height -
                            lock_base_height +
                            0.2,
                        d = thread_root_diameter
                    );
            }


        // First internal thread
        translate([
            0,
            0,
            thread_start_height
        ])
            internal_thread_ridge(0);


        // Second internal thread
        translate([
            0,
            0,
            thread_start_height
        ])
            internal_thread_ridge(180);


        // Male luer sealing cone
        translate([
            0,
            0,
            lock_base_height
        ])

            cylinder(
                h  = luer_length,
                d1 = luer_base_diameter,
                d2 = luer_tip_diameter
            );
    }
}


// ============================================================
// LUER FLOW PASSAGE
// ============================================================

module male_luer_lock_bore() {

    translate([0, 0, -0.2])

        cylinder(
            h =
                lock_base_height +
                luer_length +
                0.4,
            d = luer_bore_diameter
        );
}


// ============================================================
// COMPLETE TEST CONNECTOR
// ============================================================

module male_luer_lock() {

    difference() {

        male_luer_lock_solid();

        male_luer_lock_bore();
    }
}


// ============================================================
// MAIN TUBE SOLID
// ============================================================

module complete_solid() {

    union() {

        // Main hanging tube
        cylinder(
            h = tube_height,
            r = outer_radius
        );


        // Transition from tube to luer connector
        translate([0, 0, tube_height])

            cylinder(
                h  = transition_height,
                d1 = outer_radius * 2,
                d2 = lock_collar_outer_diameter
            );


        // Male luer-lock connector
        translate([
            0,
            0,
            tube_height + transition_height
        ])

            male_luer_lock_solid();
    }
}


// ============================================================
// COMPLETE INTERNAL FLOW PASSAGE
// ============================================================

module complete_bore() {

    // Main circular tube passage
    translate([0, 0, -1])

        cylinder(
            h = tube_height + 1.1,
            r = inner_radius
        );


    // Smooth reduction into luer bore
    translate([
        0,
        0,
        tube_height - 0.1
    ])

        cylinder(
            h =
                transition_height +
                lock_base_height +
                0.2,
            d1 = inner_radius * 2,
            d2 = luer_bore_diameter
        );


    // Passage through the male luer
    translate([
        0,
        0,
        tube_height + transition_height
    ])

        male_luer_lock_bore();
}


// ============================================================
// FINAL FULL MODEL
// ============================================================

module complete_model() {

    difference() {

        complete_solid();

        complete_bore();

        // Side groove removed.
    }
}


// ============================================================
// OUTPUT
// ============================================================

if (test_connector_only) {

    male_luer_lock();

} else {

    complete_model();
}

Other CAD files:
BuildYourOwn/laser-cut/panel.dxf
RheoBoard_PCB/RheoBoard_v1.05/3D/TCA9534APWR.step
RheoBoard_PCB/RheoBoard_v1.05/3D/Fuse 2A.stp
RheoBoard_PCB/RheoBoard_v1.05/3D/MSC.stp
BuildYourOwn/archive/laser-cut-v1/panel.dxf
RheoBoard_PCB/RheoBoard_v1.05/3D/3518P.STEP
RheoBoard_PCB/RheoBoard_v1.05/3D/AO3400A.step
RheoBoard_PCB/RheoBoard_v1.05/3D/B2B-XH-A.STEP
RheoBoard_PCB/RheoBoard_v1.05/3D/MMBT5551.stp
RheoBoard_PCB/RheoBoard_v1.05/3D/MPRLS0025PA00001A.step
RheoBoard_PCB/RheoBoard_v1.05/3D/PCA9685PW_118.step
RheoBoard_PCB/RheoBoard_v1.05/3D/PJ-082BH.step
RheoBoard_PCB/RheoBoard_v1.05/3D/TPS563203DRLR.stp
RheoBoard_PCB/RheoBoard_v1.05/3D/UCC27511A-Q1 .stp

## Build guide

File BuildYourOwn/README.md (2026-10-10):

# RheoBoardOTS - DIY

This folder is RheoBoardOTS - DIY: a flat 3D-printed panel, two air pumps, one valve, an ESP32 with BLE, a Qwiic MicroPressure sensor, and a REP (retraction-extrusion pulse).

Start on the [Main (DIY)](https://github.com/The-Hybrid-Atelier/RheoBoard/wiki/Main-(DIY)) wiki page.

Design files are in `cad/`, parts and wiring notes are in `hardware/`, and photos are in `images/`.

License: hardware CERN-OHL-W-2.0, firmware MIT, documentation CC BY-SA 4.0 — see [`../LICENSE`](../LICENSE).

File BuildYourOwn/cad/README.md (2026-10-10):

# CAD

Design files for the RheoBoardOTS - DIY flat panel and sensing tube. Print notes are on the [Parts to 3D print](https://github.com/The-Hybrid-Atelier/RheoBoard/wiki/Parts-to-3D-print) wiki page.

`encloser/` holds the panel. The folder name stays `encloser/`. `connector/` holds the sensing tube and small connector.

License: hardware CERN-OHL-W-2.0 — see [`../../LICENSE`](../../LICENSE).

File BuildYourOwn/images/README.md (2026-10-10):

# Images

Project and component photos for RheoBoardOTS - DIY. These photos support the purchased parts on the [Parts to buy](https://github.com/The-Hybrid-Atelier/RheoBoard/wiki/Parts-to-buy) wiki page.

`teaser.jpg` is the assembled bench prototype. The component photos are `esp32-thing-plus.jpg`, `qwiic-micropressure.jpg`, `qwiic-button.jpg`, `adafruit-attiny1616-seesaw.jpg`, `adafruit-4699-air-pump.jpg`, `adafruit-4663-air-valve.jpg`, `power-adapter-alt-1202.jpg`, and `l298n-motor-driver.jpg`. Vendor photos stay under their owners' terms and are here so a builder can recognize the part.

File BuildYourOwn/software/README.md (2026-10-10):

# Moved

The ESP32 sketch and its install notes are in `../../code/firmware/`. RheoData notes are in `../../code/software/`. Install and connect steps are on the [Code](https://github.com/The-Hybrid-Atelier/RheoBoard/wiki/Code) wiki page.

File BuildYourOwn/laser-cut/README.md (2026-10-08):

# Laser-cut panel

Use [`panel.svg`](panel.svg) or [`panel.dxf`](panel.dxf) to cut the mounting panel for the
rheometer components.

License: CERN-OHL-W-2.0 — see [`../../LICENSE`](../../LICENSE).

Version 1 placement: both pumps are rotated 90° with VALVE2 centered between them.
The two-pump L298N is on the left, the valve L298N is on the right, MPRLS is directly below
VALVE2, and the seesaw, ESP32, and Button are behind the drivers. PWR, VALVE1, and the former
chamber/bulkhead hole are removed.

## Specifications

- Material: 3 mm acrylic
- Finished size: 230 × 200 mm
- Mounting: zip ties through the cut slots; four feet at the corner holes

Physical envelopes used for version 1 placement:

- Pumps: Adafruit 4699 / ZR370-02PM, **58.2 × Ø27.0 mm nominal**; the placement outline uses
  the tolerance-max 58.3 × 27.2 mm body, rotated 90°
- VALVE2: Adafruit 4663 / FA0520E, **36.02 × 14.5 mm** top-view envelope
- ATtiny1616 seesaw: **25.5 × 17.8 mm**
- ESP32 Thing Plus WRL-15663: **64.77 × 22.86 mm**
- SparkFun MPRLS and Qwiic Button: **25.4 × 25.4 mm** each
- L298N modules: retained placeholder outlines because generic module dimensions vary; test-fit
  the exact boards before cutting

The pump, valve, and MPRLS envelopes do not reserve pneumatic tube bend radius. Confirm port and tubing
clearance when you place parts on the paper pattern.

## Files

- [`panel.svg`](panel.svg) — vector file for most laser-cutting software
- [`panel.dxf`](panel.dxf) — alternate vector file for software that requires DXF
- [`panel-placement-map.png`](panel-placement-map.png) — component positions and zip-tie routing
- [`panel-cut-lines.png`](panel-cut-lines.png) — visual reference for the cut geometry

## Cut the panel

1. Open `panel.svg` or `panel.dxf` in the laser-cutter software.
2. Confirm the imported panel measures exactly **230 × 200 mm**. Do not scale it.
3. Print the design at 1:1 scale on paper or make a low-cost cardboard test cut.
4. Place every real component over the test pattern and verify its slots against
   [`panel-placement-map.png`](panel-placement-map.png).
5. Run a kerf test on scrap 3 mm acrylic. Apply the measured compensation in the cutter software.
6. Use the machine manufacturer's acrylic power, speed, focus, ventilation, and fire-safety
   guidance. Never cut PVC or unknown plastic.
7. Cut the panel and let it cool before handling.

Power, speed, and kerf values are intentionally not specified because they depend on the laser and
acrylic. Record the verified settings after the first successful cut.

## After cutting

1. Remove the protective film and clean any sharp or melted edges.
2. Check the overall dimensions, corner holes, and every zip-tie slot.
3. Install the four feet.
4. Position components using `panel-placement-map.png`; version 1 has no VALVE1 or chamber position.
5. Loosely install the zip ties, confirm cable and tube clearance, then tighten and trim them.
6. Continue with
   [Step 02 — Connect electronics and tubing](../README.md#step-02-connect-electronics-and-tubing).

## Modify or regenerate the design

Edit [`generate_panel_vector.py`](generate_panel_vector.py), then regenerate both vector formats:

```bash
python3 generate_panel_vector.py
```

Do not hand-edit only one export; `panel.svg` and `panel.dxf` must remain synchronized.

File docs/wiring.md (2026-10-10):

# Wiring

Step 02 of the [assembly instructions](https://github.com/The-Hybrid-Atelier/RheoBoard/wiki/Assembly-instructions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) is the electronic and tube connection sequence for two pumps and one valve. The diagram is in `BuildYourOwn/hardware/electronic-wiring/`. The port table is in `BuildYourOwn/hardware/tube-wiring/`.

License: CC BY-SA 4.0 — see [Certification](https://github.com/The-Hybrid-Atelier/RheoBoard/wiki/Certification).

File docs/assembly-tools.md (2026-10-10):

# Tools you may need

The tool list is on the [Assembly tools](https://github.com/The-Hybrid-Atelier/RheoBoard/wiki/Assembly-tools) wiki page. The [assembly instructions](https://github.com/The-Hybrid-Atelier/RheoBoard/wiki/Assembly-instructions#before-you-start) list the same tools before Step 01.

TODO: tools the build needs that are not named in the repository yet.

License: CC BY-SA 4.0 — see [Certification](https://github.com/The-Hybrid-Atelier/RheoBoard/wiki/Certification).

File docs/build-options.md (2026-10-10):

# Build options

The three ways to build are on the [Build options](https://github.com/The-Hybrid-Atelier/RheoBoard/wiki/Build-options) wiki page: [Main (DIY)](https://github.com/The-Hybrid-Atelier/RheoBoard/wiki/Main-(DIY)), [Main (PCB)](https://github.com/The-Hybrid-Atelier/RheoBoard/wiki/Main-(PCB)), and [Main (Portable)](https://github.com/The-Hybrid-Atelier/RheoBoard/wiki/Main-(Portable)).

Pictures from this repository used with that page:

- [`img/panel/diy-annotated.jpg`](img/panel/diy-annotated.jpg)
- [`../RheoBoard_PCB/images/pcb-schematic-and-v1-board.png`](../RheoBoard_PCB/images/pcb-schematic-and-v1-board.png)
- [`img/portable/portable-concept.jpg`](img/portable/portable-concept.jpg)

Board files are in [`../RheoBoard_PCB/README.md`](../RheoBoard_PCB/README.md).

The RheoBoardPipette - Portable 3D-printed parts are not in the repository yet. TODO: those print files.

License: CC BY-SA 4.0 — see [Certification](https://github.com/The-Hybrid-Atelier/RheoBoard/wiki/Certification).

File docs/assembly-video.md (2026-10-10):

# Assembly video

TODO: assembly video.

License: CC BY-SA 4.0 — see [Certification](https://github.com/The-Hybrid-Atelier/RheoBoard/wiki/Certification).

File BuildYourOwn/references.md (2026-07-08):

# References

External datasheets, standards, and third-party library notes the design depends on. Link out
rather than duplicating content, and note the revision/date you relied on since datasheets and
standards change over time.

| Component/Standard | Link | Notes |
|---|---|---|
| SparkFun ESP32 Thing Plus (micro-USB, WRL-15663) | https://www.sparkfun.com/sparkfun-esp32-thing-plus.html | MCU for this design's firmware; plain ESP32-WROOM-32D/E (not S2/S3); [hardware repo](https://github.com/sparkfun/ESP32_Thing_Plus); schematic/graphical datasheet vendored in `references/datasheets/` |
| SparkFun Qwiic MicroPressure (MPRLS) | https://www.sparkfun.com/sparkfun-qwiic-micropressure-sensor.html | I2C `0x18`; [hardware repo](https://github.com/sparkfun/MicroPressure_Sensor) |
| SparkFun Qwiic Button (red, BOB-15932) | https://www.sparkfun.com/sparkfun-qwiic-button.html | Required in this design (1-click=REP, hold=blow); default I2C `0x6F`; [hardware repo](https://github.com/sparkfun/Qwiic_Button) |
| Adafruit 4700 air pump / vacuum (ZR320-02PM) | https://www.adafruit.com/product/4700 | ~4.5 V, 1.8 LPM; flow fixed by port plumbing; datasheet in `references/datasheets/ZR320-02PM_4.5V.pdf` |
| Adafruit 4663 air valve (FA0520E) | https://www.adafruit.com/product/4663 | 6 V 3-port flip valve; datasheet in `references/datasheets/4663_C14660_DC_6V.pdf` |
| Adafruit silicone tubing 3 mm ID | https://www.adafruit.com/product/4664 | For 4700 pumps and 4663 valve ports |
| Honeywell MPR series datasheet | vendored: `references/datasheets/Honeywell_MPR_Series_Datasheet.pdf` | Source: https://cdn.sparkfun.com/assets/2/e/8/0/9/honeywell-mpr-datasheet.pdf |
| ESP32 Thing Plus schematic | vendored: `references/datasheets/ESP32_Thing_Plus_Schematic.pdf` | SparkFun v2.0 Eagle schematic export |
| ESP32 Thing Plus graphical datasheet | vendored: `references/datasheets/ESP32_Thing_Plus_Graphical_Datasheet.pdf` | Pinout diagram, power specs |
| Qwiic Button schematic | vendored: `references/datasheets/Qwiic_Button_Schematic.pdf` | SparkFun Eagle schematic export |
| L298N (ST) | https://www.st.com/resource/en/datasheet/l298.pdf | Dual H-bridge IC datasheet (generic module, no single canonical vendor page) |
| ESP32 Arduino core (Espressif) | https://espressif.github.io/arduino-esp32/package_esp32_index.json | Boards Manager URL |
| SparkFun Qwiic Button library | https://github.com/sparkfun/SparkFun_Qwiic_Button_Arduino_Library | Arduino Library Manager |
| SparkFun MicroPressure library | https://github.com/sparkfun/SparkFun_MicroPressure_Arduino_Library | Arduino Library Manager |
| **ThingPlusBLEOSC** | https://github.com/cearto/ThingPlusBLEOSC | BLE + OSC transport for RheoData; MIT license; not on Library Manager — `git clone` into Arduino `libraries/`. Depends on **OSC** (Adrian Freed, Library Manager) and **ESP32 BLE Arduino** (Neil Kolban, usually bundled with the `esp32` core). |

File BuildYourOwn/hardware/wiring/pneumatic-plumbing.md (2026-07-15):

# Pneumatic plumbing

Text companion to [`tube-connection.png`](tube-connection.png). Tubing: **3 mm ID silicone**
([Adafruit 4664](https://www.adafruit.com/product/4664) or equivalent).

## Components

| Label | Part | Port usage |
|---|---|---|
| PUMP1 | [Adafruit 4700](https://www.adafruit.com/product/4700) ZR320-02PM (vacuum) | **Side port** (inlet) → VALVE2 metal pole; **tubing port** (outlet) → atmosphere |
| PUMP2 | Adafruit 4700 ZR320-02PM (pressure) | **Tubing port** (outlet) → VALVE2 plastic pole; **side port** (inlet) → atmosphere |
| VALVE2 | [Adafruit 4663](https://www.adafruit.com/product/4663) FA0520E | Metal pole (OFF) = vacuum path; plastic pole (ON) = pressure path; common → shared line |
| Sensor | [SparkFun Qwiic MicroPressure](https://www.sparkfun.com/sparkfun-qwiic-micropressure-sensor.html) (MPRLS) | Teed into shared line |
| Output | Chamber / nozzle | Bottom of shared line — "the line we sense" |

### Pump note (4700)

The ZR320-02PM always draws air in through the **side port** and pushes it out the **tubing port**.
Reversing motor wires does **not** flip flow direction — retract vs extrude is set by **which port
is plumbed to the valve** and which is open to atmosphere, not by L298N direction wiring.

Adafruit recommends ~**50% duty cycle** for the 4700 (not continuous run). Firmware REP timing +
`rheo/rep/pull/power` and `rheo/rep/push/power` defaults should respect this.

## Valve logic (VALVE2)

| VALVE2 state | seesaw pin 5 | Path |
|---|---|---|
| OFF (suck / retract) | LOW | Common → metal pole → PUMP1 vacuum |
| ON (blow / extrude) | HIGH | Common → plastic pole → PUMP2 pressure |

Idle pump not selected is disconnected through the valve — no plug or seal needed.

## REP cycle (firmware)

Matches the firmware phases: **baseline → retract (PUMP1) → extrude (PUMP2) → relax**.

1. **Baseline** — pumps off, ambient pressure sampling.
2. **Retract** — VALVE2 OFF, PUMP1 on (vacuum).
3. **Extrude** — VALVE2 ON, PUMP2 on (pressure, with optional ramp).
4. **Relax** — tail of fixed 1500 ms REP window.

Trigger via BLE (`rheo/rep`), Qwiic button (single click), onboard button, or USB serial `REP`.
Full API: [`../../software/rheometer-firmware/README.md`](../../software/rheometer-firmware/README.md).

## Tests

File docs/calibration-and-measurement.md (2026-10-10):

# Calibration and measurement

[Step 05 — Calibrate and use](https://github.com/The-Hybrid-Atelier/RheoBoard/wiki/Assembly-instructions#step-05-calibrate-and-use) in the assembly
instructions is split into two headings, using the lines that were already in that step:

- [Calibrate](https://github.com/The-Hybrid-Atelier/RheoBoard/wiki/Assembly-instructions#calibrate)
- [Measure](https://github.com/The-Hybrid-Atelier/RheoBoard/wiki/Assembly-instructions#measure)

The assembly instructions name the sample container (a GL45 lab reagent bottle is recommended; a beaker,
cup, or any other fluid container is also fine) and the probe. Exactly two models are still to be
added, both TODO because the files are not in the repo: one GL45 two-port cap, and one tube that
connects to that GL45 cap. The probe also uses the Adafruit 4661 tube. `sensing_tube.stl` and
`connector_small.stl` are not those parts. RheoData download, pairing, the connected indicator,
and how to start and name a REP stay TODO; they will be specified later in software and firmware.

License: CC BY-SA 4.0 — see [Certification](https://github.com/The-Hybrid-Atelier/RheoBoard/wiki/Certification).

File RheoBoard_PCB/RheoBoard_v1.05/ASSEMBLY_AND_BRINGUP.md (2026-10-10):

# RheoBoard v1.05 assembly and bringup

This revision retains two independently controlled, fixed-direction pumps and two valves. The pumps are for intermittent use. Losing communication intentionally leaves the last commanded outputs running; removing board power or sending an OFF command stops them. The board has no onboard microcontroller.

Hardware design licensing follows the repository root LICENSE, CERN-OHL-W-2.0. Documentation is CC BY-SA 4.0.

## Power and connectors

Use a regulated, center-positive 12 V DC supply with the plug dimensions required by the PJ-082BH jack: 5.5 mm outside and 2.5 mm inside. For initial testing, use a bench supply with adjustable current limiting. A 12 V, 2 A adapter is a starting selection for one board with the specified loads, subject to measured startup and simultaneous-load current. A larger adapter does not increase the board's allowable current. The input fuse is 2 A and the added eFuse has an approximately 2 A current limit.

The board makes its own 3.3 V logic supply from the 12 V input. It also makes approximately 4.52 V for pumps and 6.0 V for valves. J9 is the dedicated Qwiic master connection: its 3.3 V pin receives power from the USB/battery-powered ESP32 Thing Plus and supplies the host side of U13 and the four button pullups. U13 separates the two I²C signal domains without joining the regulated 3.3 V rails. All grounds remain common; this is not galvanic isolation.

| Connection | Pin 1 | Pin 2 | Pin 3 | Pin 4 |
| --- | --- | --- | --- | --- |
| J9 QWIIC MASTER, JST SH | GND | Host 3.3 V input | HOST_SDA | HOST_SCL |
| J1, J12, J17 QWIIC SENSOR, JST SH | GND | Local 3.3 V output | SDA | SCL |
| J3, JST EH 4-pin peripheral | GND | Local 3.3 V output | SDA | SCL |

All four JST SH connectors retain the standard Qwiic order: pin 1 GND, pin 2 3.3 V, pin 3 SDA, pin 4 SCL. Read the PCB pin-1 mark and connector drawing; a cable viewed from its mating end reverses the apparent left-to-right order. Standard Qwiic cable colors are black, red, blue and yellow in that order. [SparkFun Qwiic](https://www.sparkfun.com/qwiic).

Connect the ESP32 to **J9**, using an ordinary four-wire Qwiic cable. J1, J12 and J17 power local sensor modules from RheoBoard and share its local bus. Do not plug another independently powered controller or RheoBoard into these sensor ports. J3 provides local debug access with onboard 3.3 V and bypasses U13. The redundant J18 header has been removed.

The checked controller is SparkFun's ESP32 Thing Plus Micro-B **WRL-15663**: Qwiic SDA is GPIO23 and SCL is GPIO22, and the Qwiic power pin connects to its onboard 3.3 V regulator. Other Thing Plus variants require their own power/pin check. U13 is TCA9517ADGKR, with the RheoBoard bus on its A side and the ESP32 on its B side. Both sides have their own supply bypass and 4.7 kΩ pullups. EN follows host power. TI specifies high-impedance bus outputs when either supply is off; verify power sequencing and leakage on the assembled system. [SparkFun schematic](https://cdn.sparkfun.com/assets/6/d/c/6/c/ESP32_Thing_Plus_Schematic.pdf), [TI TCA9517A](https://www.ti.com/lit/ds/symlink/tca9517a.pdf).

## Button GPIO cable

J19 is a **five-pin, 2.54 mm button header**, separate from Qwiic and the retained J3 debug port. Fit a straight male header and connect these five leads to the ESP32. Pin 1 is the square pad; use the pin numbers and board labels rather than assuming the cable viewing direction.

| J19 pin | Button signal | Switch | ESP32 Thing Plus Micro-B connection |
| --- | --- | --- | --- |
| 1 | GND | Common return | GND |
| 2 | VALVE1_IN | SW1 | GPIO32, board label 32 |
| 3 | VALVE2_IN | SW2 | GPIO33, board label 33 |
| 4 | PUMP1_IN | SW3 | GPIO25, board label A1 |
| 5 | PUMP2_IN | SW4 | GPIO26, board label A0 |

These are recommended firmware assignments for the stated WRL-15663 controller. They are available non-strapping GPIOs and do not use Qwiic's GPIO23/22. Configure them as digital **inputs**, never driven outputs. Each button is active LOW with an existing 10 kΩ pullup and 100 nF filter (nominal 1 ms RC); add software debounce. [SparkFun schematic](https://cdn.sparkfun.com/assets/6/d/c/6/c/ESP32_Thing_Plus_Schematic.pdf), [ESP32 pin and boot configuration](https://www.espressif.com/sites/default/files/documentation/esp32_datasheet_en.pdf).

Both cables are required when using the onboard buttons: J9 supplies host 3.3 V to R16–R19, and J19 carries button signals and ground. **J19 has no power pin.** Its signals are not I²C and must not connect to SDA/SCL. Button pullups use HOST_3V3, not the RheoBoard converter's local 3.3 V, so the GPIO wiring does not join those supplies. Connect/disconnect the harness with power off; without J9 host power, the button interface is not valid.

For manual assembly, use a five-position segment of a standard straight breakaway header, such as [Adafruit 392](https://www.adafruit.com/product/392), and five short female/female leads such as [Adafruit 1950](https://www.adafruit.com/product/1950). The ESP32 also needs mating male headers. Verify the selected header's fit and pin numbering before soldering, and secure the unkeyed leads against reversal or a one-pin offset.

## Multiple boards

The working system configuration uses an external TCA9548A multiplexer: one RheoBoard per channel, up to eight boards per multiplexer. The master and multiplexer use the master's 3.3 V supply. Each RheoBoard receives 12 V and connects **GND, master-supplied 3.3 V, channel SDA and channel SCL to J9**, preserving the standard four-wire Qwiic connection. The mux switches SDA/SCL; its master-supplied 3.3 V can feed every J9 host interface. All grounds are common. The boards' local 3.3 V outputs remain separate. A bare-header mux module such as Adafruit 2717 needs a correctly pinned Qwiic adapter harness.

Set the mux to 7-bit address **0x71**: A0 high, A1 and A2 low. Select exactly one channel by writing `1 << channel` to its control register and ending the transaction with STOP. Deselect all channels with `0x00`. The branch devices keep the same addresses on every board:

| Device | Address | Purpose |
| --- | --- | --- |
| U5 Honeywell MPRLS | 0x18 | Pressure |
| U7 PCA9685, all address jumpers open | 0x40 | Pumps, valves and indicators |

The TCA9534 has been removed, so there is no onboard device at 0x3F. Each connected four-button bank needs four separate ESP32 input GPIOs plus ground; the I²C mux does not multiplex J19. Do not join button signals from different boards. J19 may remain unconnected on boards whose onboard buttons are not used.

The PCA9685 responds to All Call address 0x70 after reset. Disable All Call during initialization and keep SUB1, SUB2 and SUB3 disabled; their default programmed addresses include 0x71. Do not use a mux at 0x70 with this setup. Changing the PCA address jumpers alone does not resolve the fixed pressure-sensor address collision. [TI mux datasheet](https://www.ti.com/lit/ds/symlink/tca9548a.pdf), [NXP PWM datasheet](https://www.nxp.com/docs/en/data-sheet/PCA9685.pdf).

Start at 100 kHz with short wiring. Each board has 4.7 kΩ pullups on each side of U13. Include the selected channel's host pullups and the mux module's pullups in the combined resistance and rise-time check; keep the total selected host-segment pullup current within 3 mA. On the selected mux branch specifically, keep the effective pullup resistance **at least 2.2 kΩ per signal**, including parallel module resistors and their tolerances. This limits the voltage drop through the mux's pass switch while it acknowledges commands, preserving U13 B's 0.45 V input limit. The board's 4.7 kΩ alone satisfies this condition; 4.7 kΩ in parallel with an extra 2.2 kΩ does not. Check the actual mux module's resistors. Local sensor-module pullups also combine on the local side. Keep unpowered branches deselected. Confirm signal low levels and rise times with the actual harness before increasing speed or length; the interface is limited to 400 kHz.

Enable **exactly one mux channel at a time**. In addition to duplicate device addresses, TI prohibits joining TCA9517A B sides together. Do not put a B-side repeater or rise-time accelerator upstream of J9. The selected ESP32 and a passive-switch TCA9548A arrangement were checked; arbitrary Qwiic hubs, repeaters and cable combinations are not covered by that check. [TI interface restrictions](https://www.ti.com/lit/ds/symlink/tca9517a.pdf).

Provide pullups on the master side of the mux and keep its active-low RESET input pulled high to the master's 3.3 V supply; account for resistors already fitted to the selected module. Connect RESET to a suitable master GPIO for bus recovery. If a branch loses power or holds SDA/SCL low, a hardware reset can disconnect all branches even when an I²C command cannot get through. Serialize channel selection and each board transaction so two software tasks cannot switch channels underneath one another.

## Assembly completion

Use the revised BOM's exact manufacturer part numbers and footprints. The SMT placement file excludes through-hole and manually fitted parts. J2, J3, J19, the two valve headers and the pumps require the manual assembly steps shown in the BOM. U9 and U10 identify the fitted valve headers; the two external FA0520E valves are separately listed accessories.

Inspect the fuse, all three inductors, diode bands, IC pin-1 marks and electrolytic polarities. Q11 is the SOT-223 input MOSFET: pin 1 gate, pin 2/tab drain to the fused jack input, pin 3 source to VIN_RAW. D37's banded cathode faces VIN_RAW/source, and its anode connects to the gate. Confirm these against the new placement preview; the old v1 preview shows D1 instead. Confirm the valve cable polarity against the header markings before insertion. Check pump terminal polarity and support the pump bodies mechanically; soldered wires are not mechanical mounts. Fit the valve bodies and hoses without loading the connectors or sensor port.

The specified pump's drawing gives a 27.0 ±0.2 mm plastic-head diameter and 24.0 ±0.3 mm motor-can diameter. Its body length is 58.2 ±0.1 mm, with a further 6.1 ±0.2 mm axial nozzle projection. Reserve additional room for tubing and its bend radius. The drawing does not dimension the side nozzle's radial reach or guarantee the PCB terminal-hole fit, so check the supplied pumps and hose routing physically. [Pump dimension drawing](https://cdn-shop.adafruit.com/product-files/4699/4699_C14656_diagram.jpg).

The [JLCPCB top placement](Archive_v1_outputs/8815214A_Y73_SMT026093063736_top.png) belongs to v1 order 8815214A_Y73 / SMT026093063736. A new v1.05 order requires a new placement preview matching the revised BOM and placement export.

## Controller initialization and channel map

**Accepted prototype risk:** U5's reset pin retains a pull-up and TP3 access. The maintainer requested no reset-circuit change. Waiting in firmware alone does not guarantee the required reset; reliable startup and recovery remain unmeasured. See the retained [startup finding](Verification/REVIEW_REPORT.md).

For cold startup, keep all loads OFF until the three rails are stable. There is no TCA9534 initialization in this revision. Configure U7 for non-inverted totem-pole outputs; initialize its used channels FULL OFF, disable All Call/Sub Call addressing, set its common frequency using the specified sleep/prescaler sequence, wake the oscillator and wait at least 500 µs. [NXP PCA9685 datasheet](https://www.nxp.com/docs/en/data-sheet/PCA9685.pdf).

| Function | Controller channel | Physical circuit |
| --- | --- | --- |
| Pump 1 | PCA9685 LED0 | U8, Q3 |
| Pump 2 | PCA9685 LED1 | U11, Q4 |
| Indicators | PCA9685 LED2–LED4 | Existing indicators, unchanged |
| Valve 1 | PCA9685 LED5, pin 11 | U10, Q10, gate resistor R55 |
| Valve 2 | PCA9685 LED6, pin 12 | U9, Q8, gate resistor R36 |
| Valve buttons | ESP32 inputs through J19 pins 2/3 | SW1/SW2, active LOW |
| Pump buttons | ESP32 inputs through J19 pins 4/5 | SW3/SW4, active LOW |

Command valves with the PCA9685's **FULL ON/FULL OFF bits**, keeping steady binary operation. In register order ON_L, ON_H, OFF_L, OFF_H, ON is `00 10 00 00` and OFF is `00 00 00 10` (hex bytes). LED5 occupies 0x1A–0x1D and LED6 0x1E–0x21. Duty value 4095 still produces PWM. This revision does not qualify reduced valve holding power.

Before sending a four-byte register block in one I²C transaction, enable **MODE1.AI = 1** (auto-increment); its reset value is 0. Otherwise, write each register at its individual address. Keep **MODE2.OCH = 0** so the channel updates at STOP, and set both FULL ON and FULL OFF fields explicitly for each command.

Pump duties remain independent at one shared frequency. Use full-OFF/full-ON for endpoints and measure the lowest reliable starting duty, adding a starting pulse if needed. Average motor drive is not calibrated flow. Pumps and valves now share U7's OE, reset, SLEEP and ALL_LED operations. Set frequency during cold initialization with loads off; do not change these global controls casually while loads are running.

Selecting another mux channel or losing communication intentionally leaves the last commanded outputs active while board power stays stable. After a master restart, read and reconcile U7's retained state before issuing new commands. Cold initialization and reconnection are different cases. Buttons require the ESP32 firmware and are not independent hardware emergency stops.

Pump rotation is not reversible with this board. Each pump moves air from its inlet to its outlet. Inflation and suction use the appropriate tube and valve connections. The pump vendor recommends roughly equal run and rest time; this duty guidance is distinct from PWM duty. [Pump specifications](https://www.adafruit.com/product/4699).

The MPRLS0025PA00001A measures 0–25 psi absolute. Convert its raw readings using the selected sensor's transfer function and subtract a measured ambient baseline when gauge pressure is required. Check its status bits and wait for conversion completion. Ambient pressure should not be assumed to read zero. [Honeywell sensor datasheet](https://automation.honeywell.com/content/dam/honeywell-edam/sps/ast/en-us/campaigns/pressure-sensors/documents/sps-siot-mpr-series-datasheet-32332628-ciid-172626.pdf).

## Hardware acceptance

These are physical measurements to record on the first assembled v1.05 boards. They remain open until performed.

| Check | Evidence to record |
| --- | --- |
| Unpowered inspection | Fitted identities and orientation; no bridges; no sustained rail-to-ground short after capacitors settle. |
| Initial power, host and loads disconnected | Input current and approximately 3.3 V, 4.52 V and 6.0 V rails. Stop for current limiting, unexpected voltage or heating. |
| Supply startup and hot plug | Scope fused input, VIN_RAW, protected VIN, Q11 gate-source voltage and all three outputs. Verify protected VIN remains within the buck's operating range, including transient peaks. |
| New reverse-polarity stage | With a current-limited test setup, verify Q11 pinout, gate voltage, voltage drop, temperature and reverse-input behavior. Live reversal needs a controlled bench test; the P-MOS alone is not an ideal-diode reverse-current controller. |
| Sensor startup and brownout | Record VDD/RES and initialization across power cycles and supply dips; the retained reset circuit is an accepted prototype risk. |
| Qwiic power states | Test host-only power, board-only power, both powered and each power-up order. Measure both 3.3 V rails for backfeed and both SDA/SCL pairs for valid levels, edges and leakage. |
| Buttons and GPIO cable | Verify J19 pin order, each switch/input mapping, inactive HIGH/pressed LOW, debounce, and host-only/board-only power behavior. |
| One load at a time | Correct physical channel, pump starting/stall current, valve operation, supply droop and flyback waveform. Keep stall tests brief and current limited. |
| Combined loads and PWM | Startup, load-step overshoot/undershoot, switching ripple, input current and temperatures over the intended run/rest cycle. |
| Communication interruption | Last commanded state remains while board power stays stable; reconnect/readback works; brownout returns to a known state. |
| Multiple boards | Select each mux channel independently, confirm the two onboard device addresses, check bus edges and absence of cross-board actuation or supply backfeed. |
| Pressure and mechanics | Ambient baseline, comparison with known pressure, hose/valve routing, leaks, connector fit and enclosure clearance. |

The four reduced bulk capacitors remain 22 µF / 50 V and bring each pump/valve rail to approximately 88.3 µF nominal, within TI's 22–110 µF recommended range. The 105.9 µF estimate applies positive initial tolerance only; it is not a full temperature/DC-bias worst case. More output capacitance is not automatically better for a compensated converter. This calculation does not establish transient stability; capacitance under bias, ESR, wiring inductance and real load behavior remain part of the measurements above. [Buck converter datasheet](https://www.ti.com/lit/gpn/tps563203).

Release repeated production only after the revised fabrication checks, supplier placement review and hardware acceptance are complete. The DIY firmware elsewhere in this repository is not automatically compatible with this PCB's channel map and initialization.

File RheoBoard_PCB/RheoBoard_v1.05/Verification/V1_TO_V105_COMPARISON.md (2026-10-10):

# RheoBoard v1 versus v1.05 — comparison checkpoint of 2026-10-09

This is a historical checkpoint. The later [PCA/button update](PCA_Control_2026-10-10/README.md) changes actuator control and adds J19; use the current review for release status.
**This detailed comparison records the 2026-10-09 design.** On 2026-10-10, D1 was subsequently replaced by Q11 DMP6023LE-13, D37 BZT52C10-7-F and R85 10 kΩ. Current totals are 167 components/features, 418 schematic pin nodes, 148 fitted parts and 142 SMT parts. The new input stage adds local routing and one ground via while preserving all 164 retained components and their connections, placement and pad geometry. See the [current review](REVIEW_REPORT.md) and [selective change verification](Altium_Features_2026-10-10/README.md). The tables below, including D1 and the 165-component/611-trace counts, remain historical evidence for the preceding checkpoint.

The saved v1.05 design adds input protection, separates the Qwiic master interface from the local sensor supply, and corrects several footprints and part specifications. The pump, valve, pressure-sensor and controller functions are retained. The board outline remains 109 × 126.4 mm with two copper layers.

This comparison is between the saved KiCad projects on 2026-10-09. The previously assembled v1 may already contain JLCPCB component substitutions that differ from its schematic labels. A changed CAD value or purchasing label does not by itself establish which part JLCPCB fitted to v1.

Updated after the authorized J18 removal on 2026-10-09. The original v1 remains unchanged. Current v1.05 exports are compared with the preserved native v1 exports; the removal check also verifies that all remaining v1.05 component values, placements and pin nets are unchanged. The pressure-sensor startup/reset and valve voltage-margin findings remain accepted prototype risks, as instructed by the maintainer.

## Schematic changes by circuit

| Item | v1 | v1.05 | Effect |
| --- | --- | --- | --- |
| Input path | J2 → F1 → D1 → VIN → converters | J2 → F1 → D1 → VIN_RAW → U12 → VIN → converters | Adds protection ahead of all three converters. |
| U12 and supporting parts | Absent | TPS259472ARPWR; R78–R81 and C64–C67 | Approximately 2 A current limit, 13.8 V nominal clamp, undervoltage control and controlled startup. These are design settings, not measurements. |
| D36 | Absent | SMBJ13A from VIN_RAW to ground | Adds input surge suppression. |
| Pump capacitors C32/C34 | 100 µF / 16 V each | 22 µF / 50 V each | Pump-rail nominal capacitance falls from 244.3 µF to 88.3 µF. |
| Valve capacitors C43/C45 | 100 µF / 16 V each | 22 µF / 50 V each | Valve-rail nominal capacitance falls from 244.3 µF to 88.3 µF. |
| R45 pump feedback | Schematic label 197 kΩ ±1% | 196 kΩ ±1% | Label-based nominal setpoint changes from 4.54 V to 4.52 V. A v1 purchasing substitution may already have used 196 kΩ. |
| R61 logic feedback | 135 kΩ ±1% label | 135 kΩ ±0.1% | Nominal 3.3 V unchanged; tighter specified tolerance. |
| R73 indicator resistor | 550 Ω label | 549 Ω ±1% | Aligns the schematic to the selected standard value. |
| Valve feedback R60/R74 | 270 kΩ / 30 kΩ | Same ratio | Nominal 6.0 V remains unchanged. |
| J9 master port | Shares local +3V3, SDA and SCL directly | HOST_3V3, HOST_SDA and HOST_SCL through U13 | Separates the ESP32 supply from the board supply while retaining a standard four-wire Qwiic connector. Ground stays common. |
| U13 and supporting parts | Absent | TCA9517ADGKR, C68/C69 100 nF, R82/R83 4.7 kΩ, R84 10 kΩ | Adds the host/local I²C interface, bypassing, host pullups and host-rail discharge. Local bus is A; host is B. |
| J1/J12/J17 sensor ports | Local 3.3 V, SDA, SCL and GND | Same connections | Continue powering local Qwiic sensor modules. |
| J3 four-pin EH port | Local bus and 3.3 V | Same connections | Retained local bus connection; this larger connector is not an SH Qwiic socket. |
| J18 service header | Absent | Removed from the intermediate v1.05 design | Existing J3 already provides local debug access. |
| D1 | SS54 schematic value/custom footprint | B540C-13-F / SMC | Aligns the CAD definition with the selected diode. Its cathode now feeds VIN_RAW. |
| F1 | Generic 2 A label | 2 A time-delay JFC1032-1200TS | Makes the selected fuse explicit. |
| L1/L2/L5 | 4.7 µH / 4 A generic label | 4.7 µH FXL0530-4R7-M | Inductance unchanged; specific purchasing identity and footprint corrected. |
| U9/U10 | VALVE and VALVE2 symbols/labels | JST XH two-pin 2.50 mm headers | Represents the actual fitted connectors; external valves are accessories. Electrical connections are retained. |
| U8/U11 pumps | Generic PUMP symbols | ZR370-02PM / 4.5 V / 2.5 LPM / approximately 500 mA | Identifies the existing pumps and normalizes symbols. No direction-control circuit is added. |
| U1/U2/U3 symbol definitions | VIN=input; SW=output; GND=power_out; BST=output | VIN=power_in; SW=power_out; GND=power_in; BST=passive | Corrects ERC pin classifications; no corresponding pin is rewired. |
| Other passive labels | Several generic or inaccurate voltage/tolerance labels | Selected capacitor dielectric, voltage and tolerance; normalized resistor labels | Mainly specification and purchasing cleanup. Exact before/after values are listed below. |
| Schematic presentation | Misleading driver/sensor/switch captions and inherited grid/cache warnings | Correct captions, grid alignment, consistent pump/PCA9685 definitions and clearer address notes | Improves readability and library/ERC consistency. The earlier 757 grid plus two pump-cache warnings were removed during v1.05 cleanup. |

All 367 original schematic pin identities remain. Only four existing pins change net names: **D1 pin 1** from VIN to VIN_RAW, and **J9 pins 2/3/4** from the local power/data nets to their HOST equivalents. Added components extend existing nets as expected. No other existing-pin connectivity group changes occur outside these power/master-interface splits.

## PCB changes by area

| Area | v1 | v1.05 |
| --- | --- | --- |
| Outline and layer count | 109 × 126.4 mm, two copper layers | Identical outline and layer count. |
| Main arrangement | Input/converters at top, controls near centre, pumps and valve connectors below | Same arrangement; 140 of 149 existing footprint origins are unchanged. Eight parts/testpoints move and F1 gets a corrected origin. |
| New input protection | No U12 cluster | U12/D36/R78–R81/C64–C67 near the input; VIN_RAW/protected VIN routed separately. |
| New host interface | J9 tied directly into local bus | U13/C68/C69/R82–R84 near the right-side master connector, with separate host routing. |
| Service header | No J18 | No J18; its three holes, two dedicated bus branches and service labels were removed. J3 is retained. |
| F1 lands and origin | Off-centre origin; two 5.00 × 3.81 mm lands with 7.18 mm centre spacing | Centred origin; 3.40 × 3.43 mm lands with 9.20 mm spacing. The pad-pair midpoint stays at (123.40, 48.01) mm. SMT classification corrected. |
| L1/L2/L5 lands | Custom pattern with 1.8 × 2.0 mm lands | FXL0530 pattern with 1.9 × 2.5 mm lands and corrected spacing/orientation. Component origins unchanged. |
| D1 footprint | Custom SS54 lands | Standard SMC pattern with cathode marking. Component origin unchanged. |
| D11/D12/D16/D18 footprints | Custom SS34 lands | Standard SMA patterns and polarity markings. Component origins unchanged. |
| C32/C34/C43/C45 footprints | CP_Elec_6.3x5.4_Nichicon | CP_Elec_6.3x5.8. Copper pad sizes are retained; C32 moves by 1.00 mm, while the other three centres remain fixed. |
| U9/U10 connector holes | 2.54 mm pitch, 0.8636 mm drills | 2.50 mm pitch, 1.00 mm drills; existing footprint origins retained. |
| TP1 | 0.50 mm copper disc despite D1.0 footprint name | 1.00 mm copper disc, moved to clear surrounding circuitry; short interrupt routing added. |
| TP2–TP9 | 0.85 mm square copper pads, 0.50 mm drills | 1.00 mm circular copper pads, same drills/locations; minimum radial ring grows from 0.175 to 0.25 mm. |
| SW1–SW4 | Generic switch footprint link | Project-local four-pad definition. Existing copper pad geometry and placement retained. |
| Existing Qwiic bodies | Four SH sockets | Same positions, orientation, pin order and pad geometry. J9 has different net assignments and MASTER labeling; other SH sockets are SENSOR ports. |
| Pump footprint locations | U8/U11 positions and 4 mm terminal holes | Retained. A 0.000001 mm native-export coordinate difference is treated as numerical normalization. Assembly category changes from SMT to through-hole. |
| Mounting holes | H1–H4 | Same centres, copper and drills. Other unchanged mechanical geometry is preserved in the exported profile/pads. |
| Routing | 527 exported copper line/arc primitives; 281 vias | 611 primitives; 301 vias. Added routing serves input protection, U13 and the moved TP1; host routing is split from local routing. |
| Filled copper | Original filled contours and teardrops | Recomputed around revised pads and routing. Contour changes include teardrops, so they must not be interpreted as entire zones being deleted. |
| Silkscreen/artwork | Rheoboard V1, generic connector/part labels | RheoBoard v1.05, MASTER/SENSOR labels and corrected footprint artwork/polarity identification. |
| Library portability | Khach Footprint/Sensor_Pressure dependencies | Standard or project-local RheoBoard library links. A library-name change does not necessarily change the physical pads. |

## Exact placement changes

Coordinates below are KiCad board millimetres, with positive Y downward. All inherited component rotations and board sides are retained. F1's origin correction is shown separately from the eight physical placement changes.

| Reference | v1 centre/origin | v1.05 centre/origin | Distance or interpretation |
| --- | --- | --- | --- |
| C29 | (161.9267, 67.6194) | (162.1500, 67.6194) | 0.223 mm |
| C30 | (160.4420, 67.6220) | (160.6500, 67.6220) | 0.208 mm |
| C32 | (178.4000, 105.2000) | (179.2000, 104.6000) | 1.000 mm |
| C33 | (146.2278, 109.8042) | (146.8000, 109.5000) | 0.648 mm |
| C46 | (143.4875, 79.7040) | (143.4875, 79.4500) | 0.254 mm |
| D15 | (161.9660, 71.1780) | (162.1500, 71.1780) | 0.184 mm |
| F1 | (125.3000, 53.3700) | (123.4000, 48.0100) | Origin recentered; pad-pair midpoint unchanged |
| R44 | (160.4420, 71.1780) | (160.6500, 71.1780) | 0.208 mm |
| TP1 | (170.0784, 78.0796) | (172.4000, 80.6500) | 3.464 mm |

## Added components

The 16 additions comprise ten input-protection parts and six Qwiic-interface parts. The redundant J18 was removed from the intermediate v1.05 design. No original component reference was removed.

| Reference | Value/part | Board position in mm |
| --- | --- | --- |
| C64 | 3.3nF 50V X7R ±10% | (148.0000, 52.5000) |
| C65 | 1uF 50V X7R ±10% | (140.5000, 43.5000) |
| C66 | 100nF 50V X7R ±10% | (144.2500, 46.6000) |
| C67 | 4.7uF 50V X7R ±10% | (146.8000, 55.3000) |
| C68 | 100nF 50V X7R ±10% | (189.0000, 109.0000) |
| C69 | 100nF 50V X7R ±10% | (193.0000, 109.0000) |
| D36 | SMBJ13A | (146.0000, 42.3000) |
| R78 | 680k ±1% | (139.0000, 46.5000) |
| R79 | 100k ±1% | (140.0000, 50.5000) |
| R80 | 390k ±1% | (141.5000, 53.7000) |
| R81 | 1.65k ±1% | (148.5000, 50.0000) |
| R82 | 4K7/0603/1% | (190.0000, 117.0000) |
| R83 | 4K7/0603/1% | (192.5000, 117.0000) |
| R84 | 10K/0603/1% | (195.5000, 114.0000) |
| U12 | TPS259472ARPWR | (144.5000, 50.5000) |
| U13 | TCA9517ADGKR | (190.7500, 112.0000) |

## Rule settings and validation

Eight PCB checks that v1 ignored are enabled in v1.05: courtyard overlap is an error; missing courtyard, silkscreen-to-edge, text height, footprint-library mismatch, footprint type mismatch, footprint-library issues and silkscreen-over-copper are warnings. Other board settings, numerical clearances, ERC settings and netclass settings are unchanged. No explicit rule exclusions were added.

Fresh post-removal v1.05 ERC reports zero errors/warnings. Saved/refilled DRC reports zero violations, unrouted connections or schematic-parity findings. Project rule settings are unchanged; current source hashes are recorded in the removal evidence. This comparison does not claim a fresh v1 ERC/DRC run.

## Functions retained

Two fixed-direction, intermittent-use pumps and two valve channels remain. The four AO3400A low-side stages and their flyback circuits retain their topology. The TPS563203 converters, PCA9685 PWM controller, TCA9534A expander, MPRLS pressure sensor, four switches and address straps remain. Communication loss still retains the last commanded state. No communication watchdog, H-bridge, active sensor reset or lower valve-voltage setting was added. Multiple boards use the external mux arrangement described in the assembly guide; the mux is not an added on-board component.

## Full component comparison

Every one of the 165 current references is included below. “Value/spec” can mean a label, tolerance or procurement correction; it does not imply that a different part was actually assembled on v1. “Pads” includes shape, size, drill or position changes. Artwork is assessed separately from connectivity. Sub-0.00001 mm export rounding is normalized.
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

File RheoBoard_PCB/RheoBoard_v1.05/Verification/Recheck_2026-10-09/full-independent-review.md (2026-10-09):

# Independent v1.05 recheck

**NEEDS ATTENTION:** the pressure sensor’s startup/reset requirement is not guaranteed by the present circuit. No source or fabrication file was changed.

Fresh KiCad checks: **ERC 0 errors/0 warnings; DRC 0 errors/0 warnings/0 unconnected/0 parity mismatches**. All 398 schematic pin connections reconcile to PCB; 61 electrical connectivity/value assertions pass. The 160 components, 86 schematic nets, pin functions/types, and purchasing metadata exactly match the completed cleanup. Native rendered schematic pixels are identical to the previously reviewed final drawing.

## New actionable finding

U5 requires a VDD rise of at least 10 V/ms, or an active reset after power stabilizes. U3 has a typical 1.4 ms softstart; 3.3 V / 1.4 ms gives an illustrative mean rise of 2.36 V/ms. U5 RES presently connects only to a 10k pull-up and TP3, with no active reset control. This creates a startup/brownout reliability gap; it does **not** establish that every board fails. Before production approval, add a guaranteed post-stable reset strategy or establish manufacturer-accepted compliance with measured waveforms. The sensor and 3.3 V supply should be scoped together.

Sources: [Honeywell MPR,§4,p11](https://automation.honeywell.com/content/dam/honeywell-edam/sps/ast/en-us/campaigns/pressure-sensors/documents/sps-siot-mpr-series-datasheet-32332628-ciid-172626.pdf), [TI TPS563203,§6.3.3](https://www.ti.com/lit/gpn/tps563203).

## Coverage and limits

Root’s fresh short/orphan/suspicious-net checks return zero. Its aggregate completes 6/6 audits with 245 resolved symbols / 1 sheet and 160 footprints / 431 pads, without diagnostics. The raw +12V decoupling error is a heuristic on the jack-to-fuse node; actual ICs have downstream bypassing. Five dedicated-rail-testpoint suggestions remain optional. Narrow JLC preflight passes, which does not resolve the sensor startup requirement or establish manufacturer acceptance.

Source hashes match the completed cleanup exactly. Prior capacitor-bias, physical geometry and mechanical review is explicitly reused with that binding; the known drawing-only IPC rectangle representation limitation remains. Actual adapter/load startup, hot-plug, brownout, thermal behavior,external mux/controller integration and exact JLC assembly preview still need qualification.

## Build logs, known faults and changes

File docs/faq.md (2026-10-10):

# FAQ

Answered questions are on the [FAQ](https://github.com/The-Hybrid-Atelier/RheoBoard/wiki/FAQ) page. They point at the [Assembly instructions](https://github.com/The-Hybrid-Atelier/RheoBoard/wiki/Assembly-instructions).

## Where are the assembly packets?

TODO

## What modifications are documented?

TODO

## How do I troubleshoot a build?

TODO

## Where is the logo?

TODO

## Who is acknowledged?

TODO

## Who sells a kit?

TODO

## Where is the community?

TODO

## How do I cite this project?

TODO

## Where is the assembly video?

TODO

License: CC BY-SA 4.0 — see [Certification](https://github.com/The-Hybrid-Atelier/RheoBoard/wiki/Certification).

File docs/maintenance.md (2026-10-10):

# Maintenance

See [Maintenance](https://github.com/The-Hybrid-Atelier/RheoBoard/wiki/Maintenance).

License: CC BY-SA 4.0 — see [Certification](https://github.com/The-Hybrid-Atelier/RheoBoard/wiki/Certification).

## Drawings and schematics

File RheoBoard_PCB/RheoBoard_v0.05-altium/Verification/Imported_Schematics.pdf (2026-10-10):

I2C

# MPRLS0025PA00001A

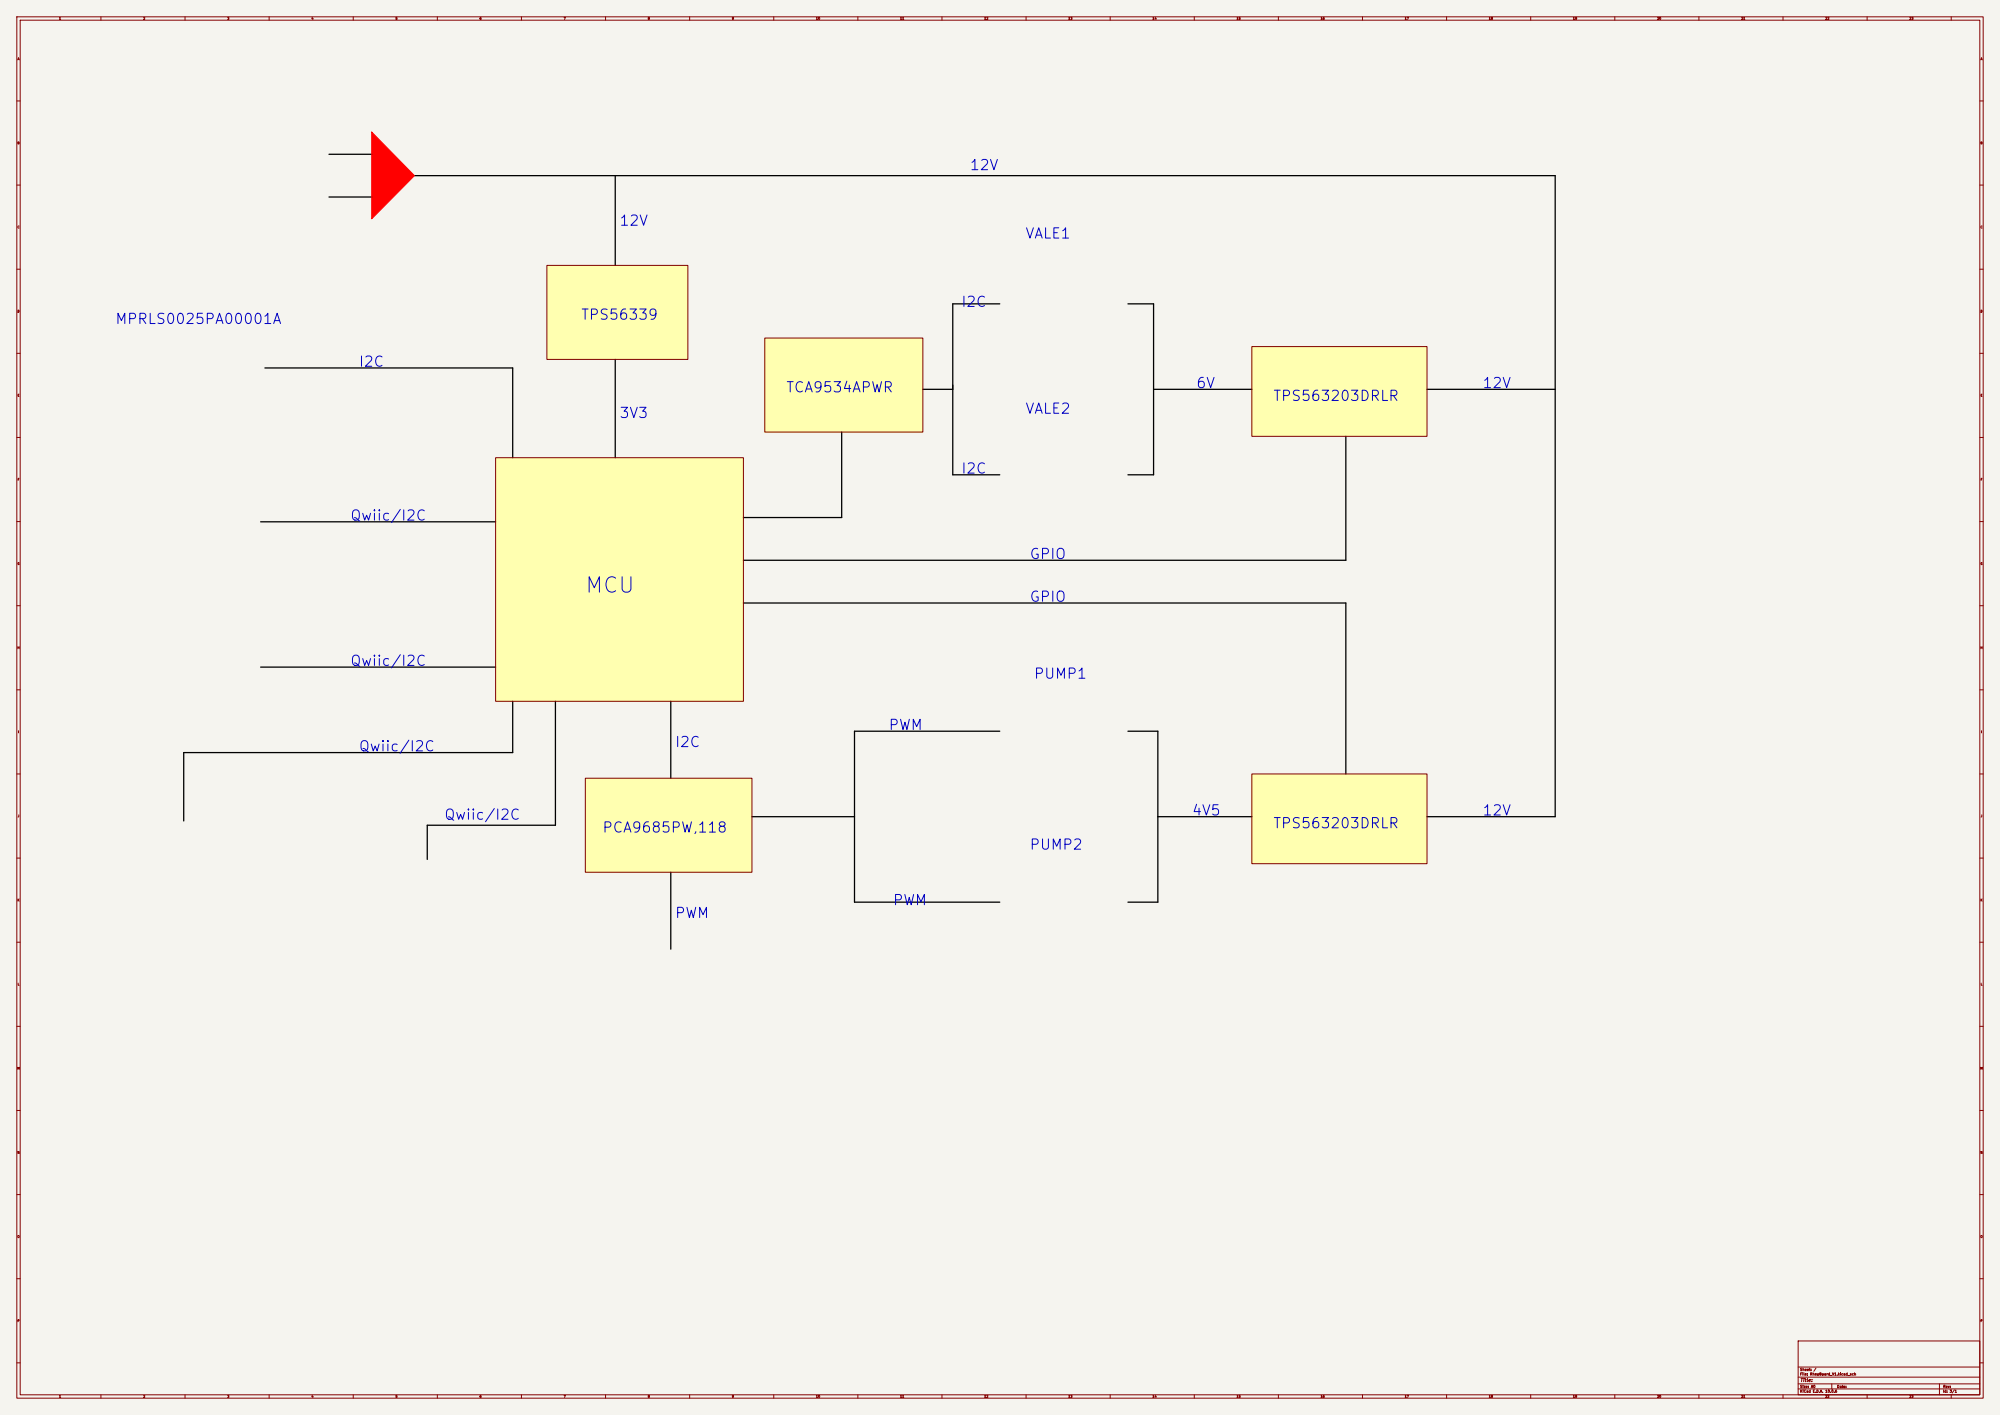
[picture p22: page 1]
FGH; IJK; P Date:; KiCad E.D.A. 10.0.6; Size: A0; Rev:; Title:; File: RheoBoard_V1.kicad_sch; Sheet: /; TPS563203DRLR; Qwiic/I2C; PWM; PCA9685PW,118 Qwiic/I2C; VALE2; GPIO; MCU; TCA9534APWR; PUMP2; PUMP1; TPS56339; VALE1

# 0.1UF,50V ²

SCL | QWIIC

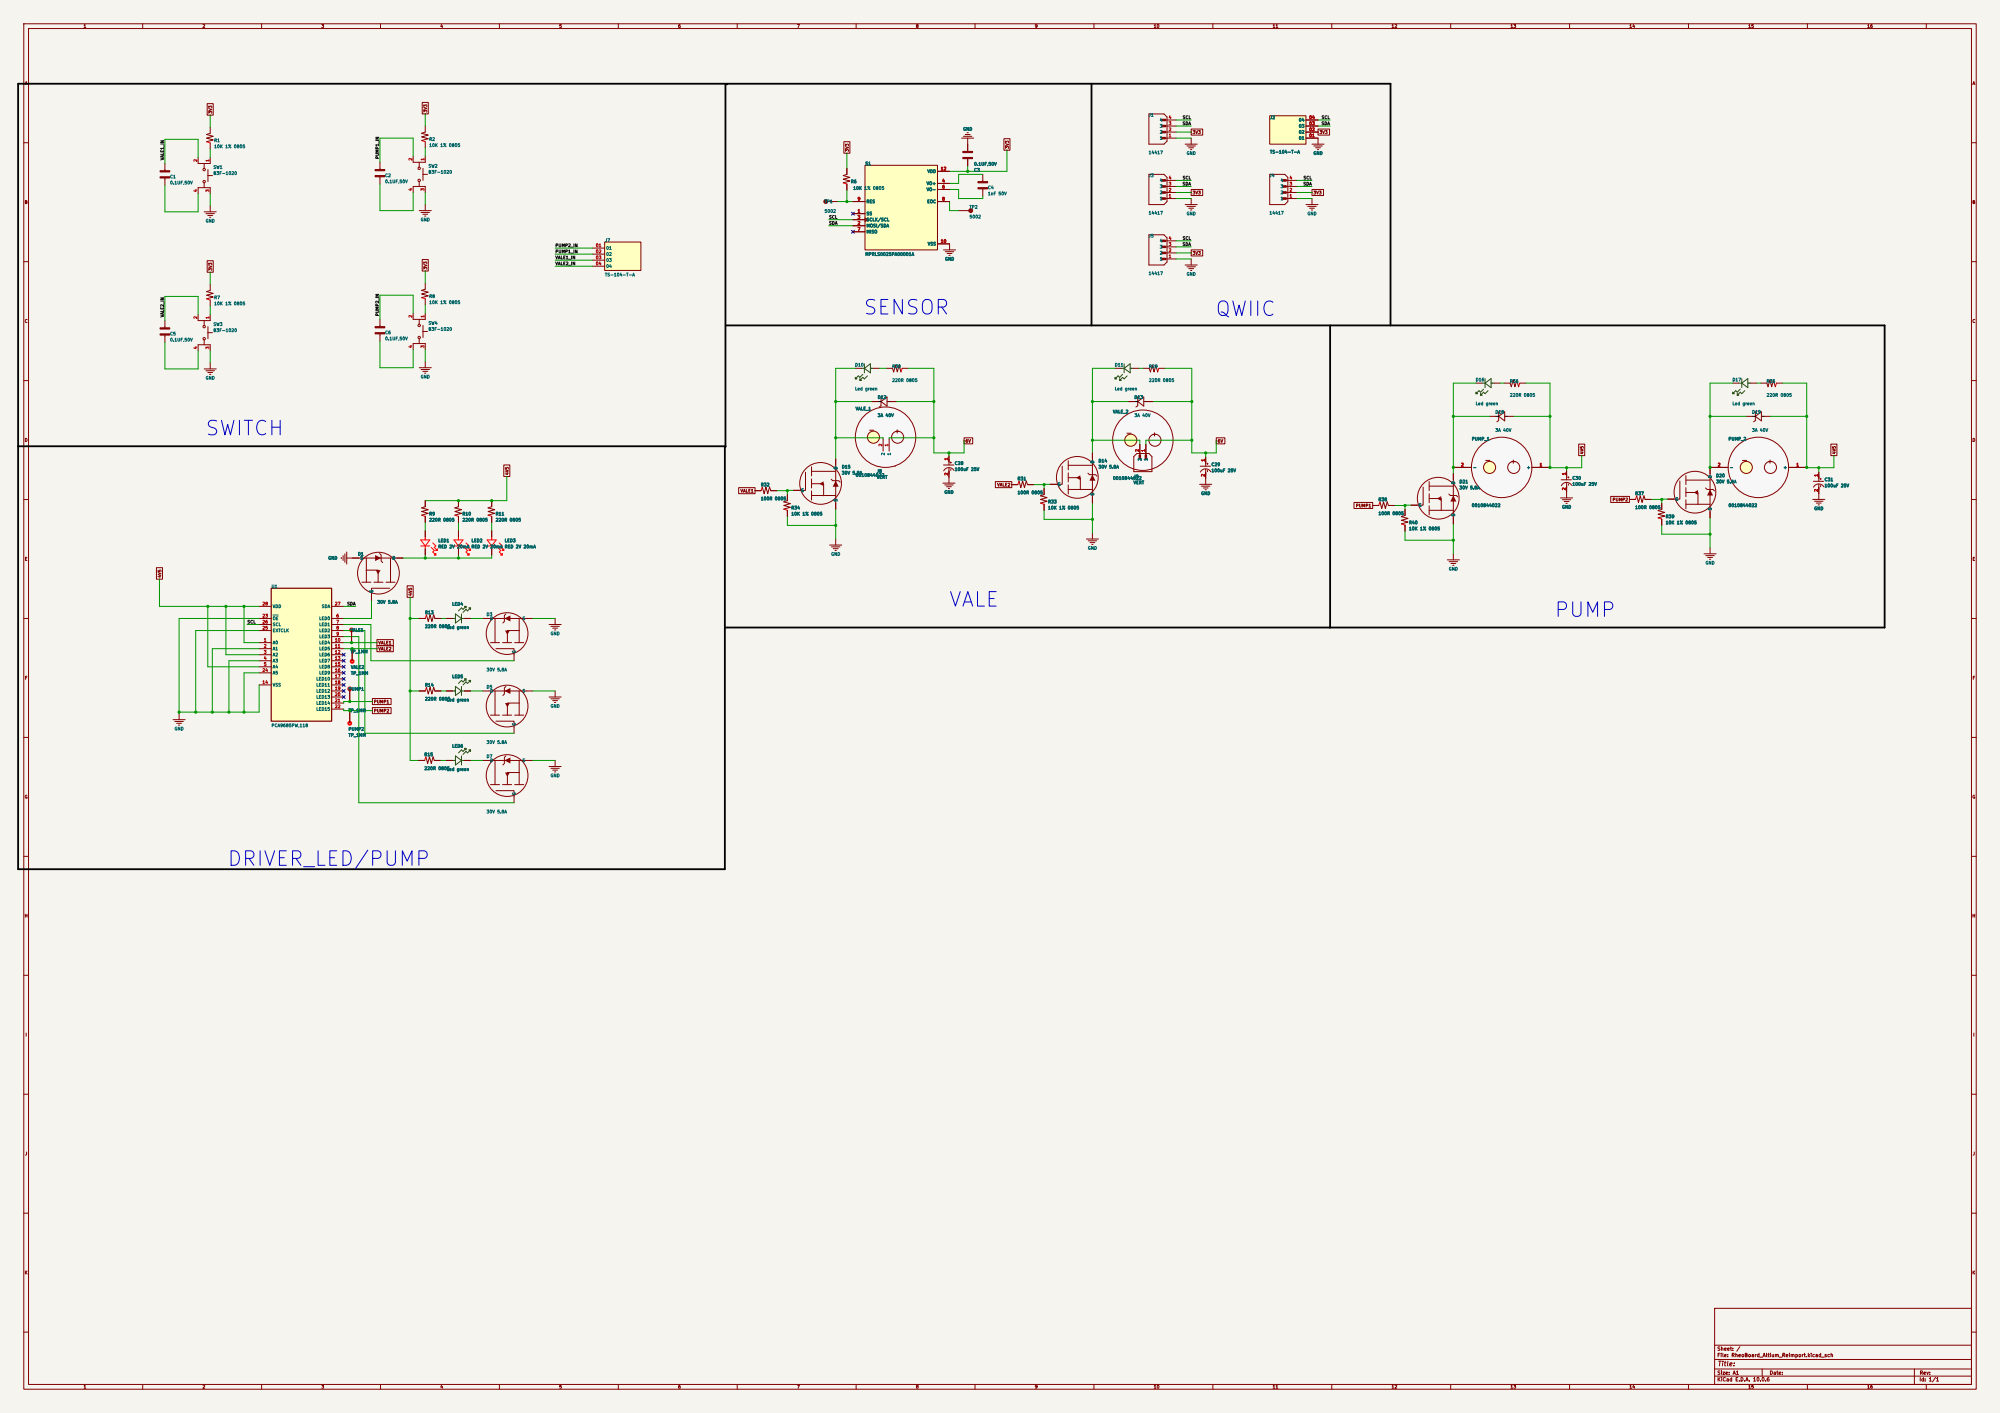
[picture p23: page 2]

DRIVER_LED/PUMP | LED2 RED 2V 20mA D1 | LED3 RED 2V 20mA

# 10UF 50V C15

# 18pF 50V R26

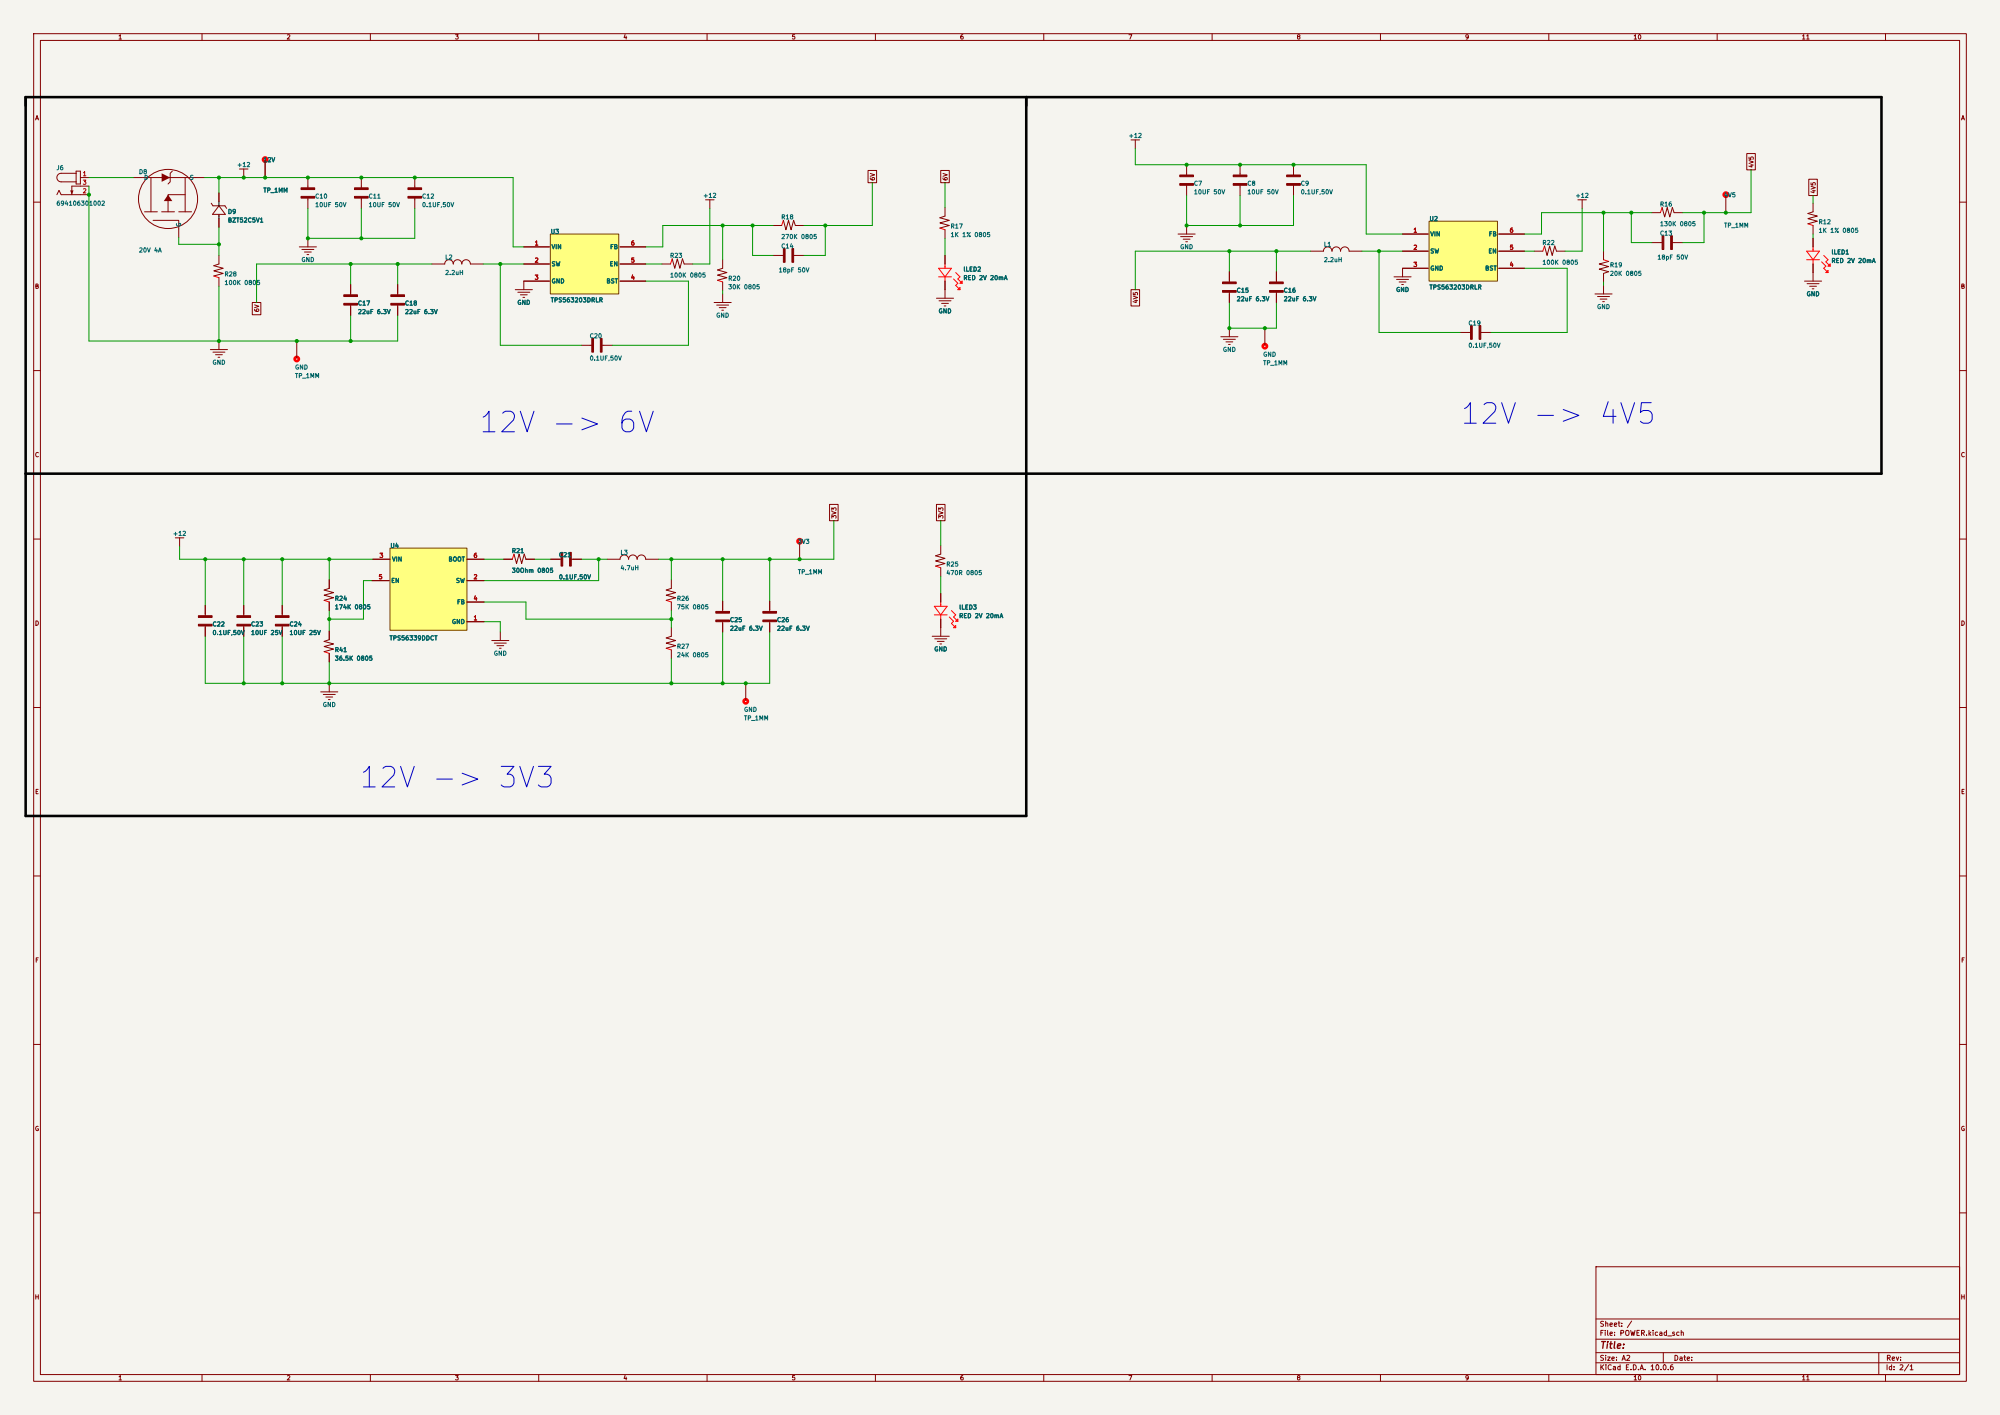
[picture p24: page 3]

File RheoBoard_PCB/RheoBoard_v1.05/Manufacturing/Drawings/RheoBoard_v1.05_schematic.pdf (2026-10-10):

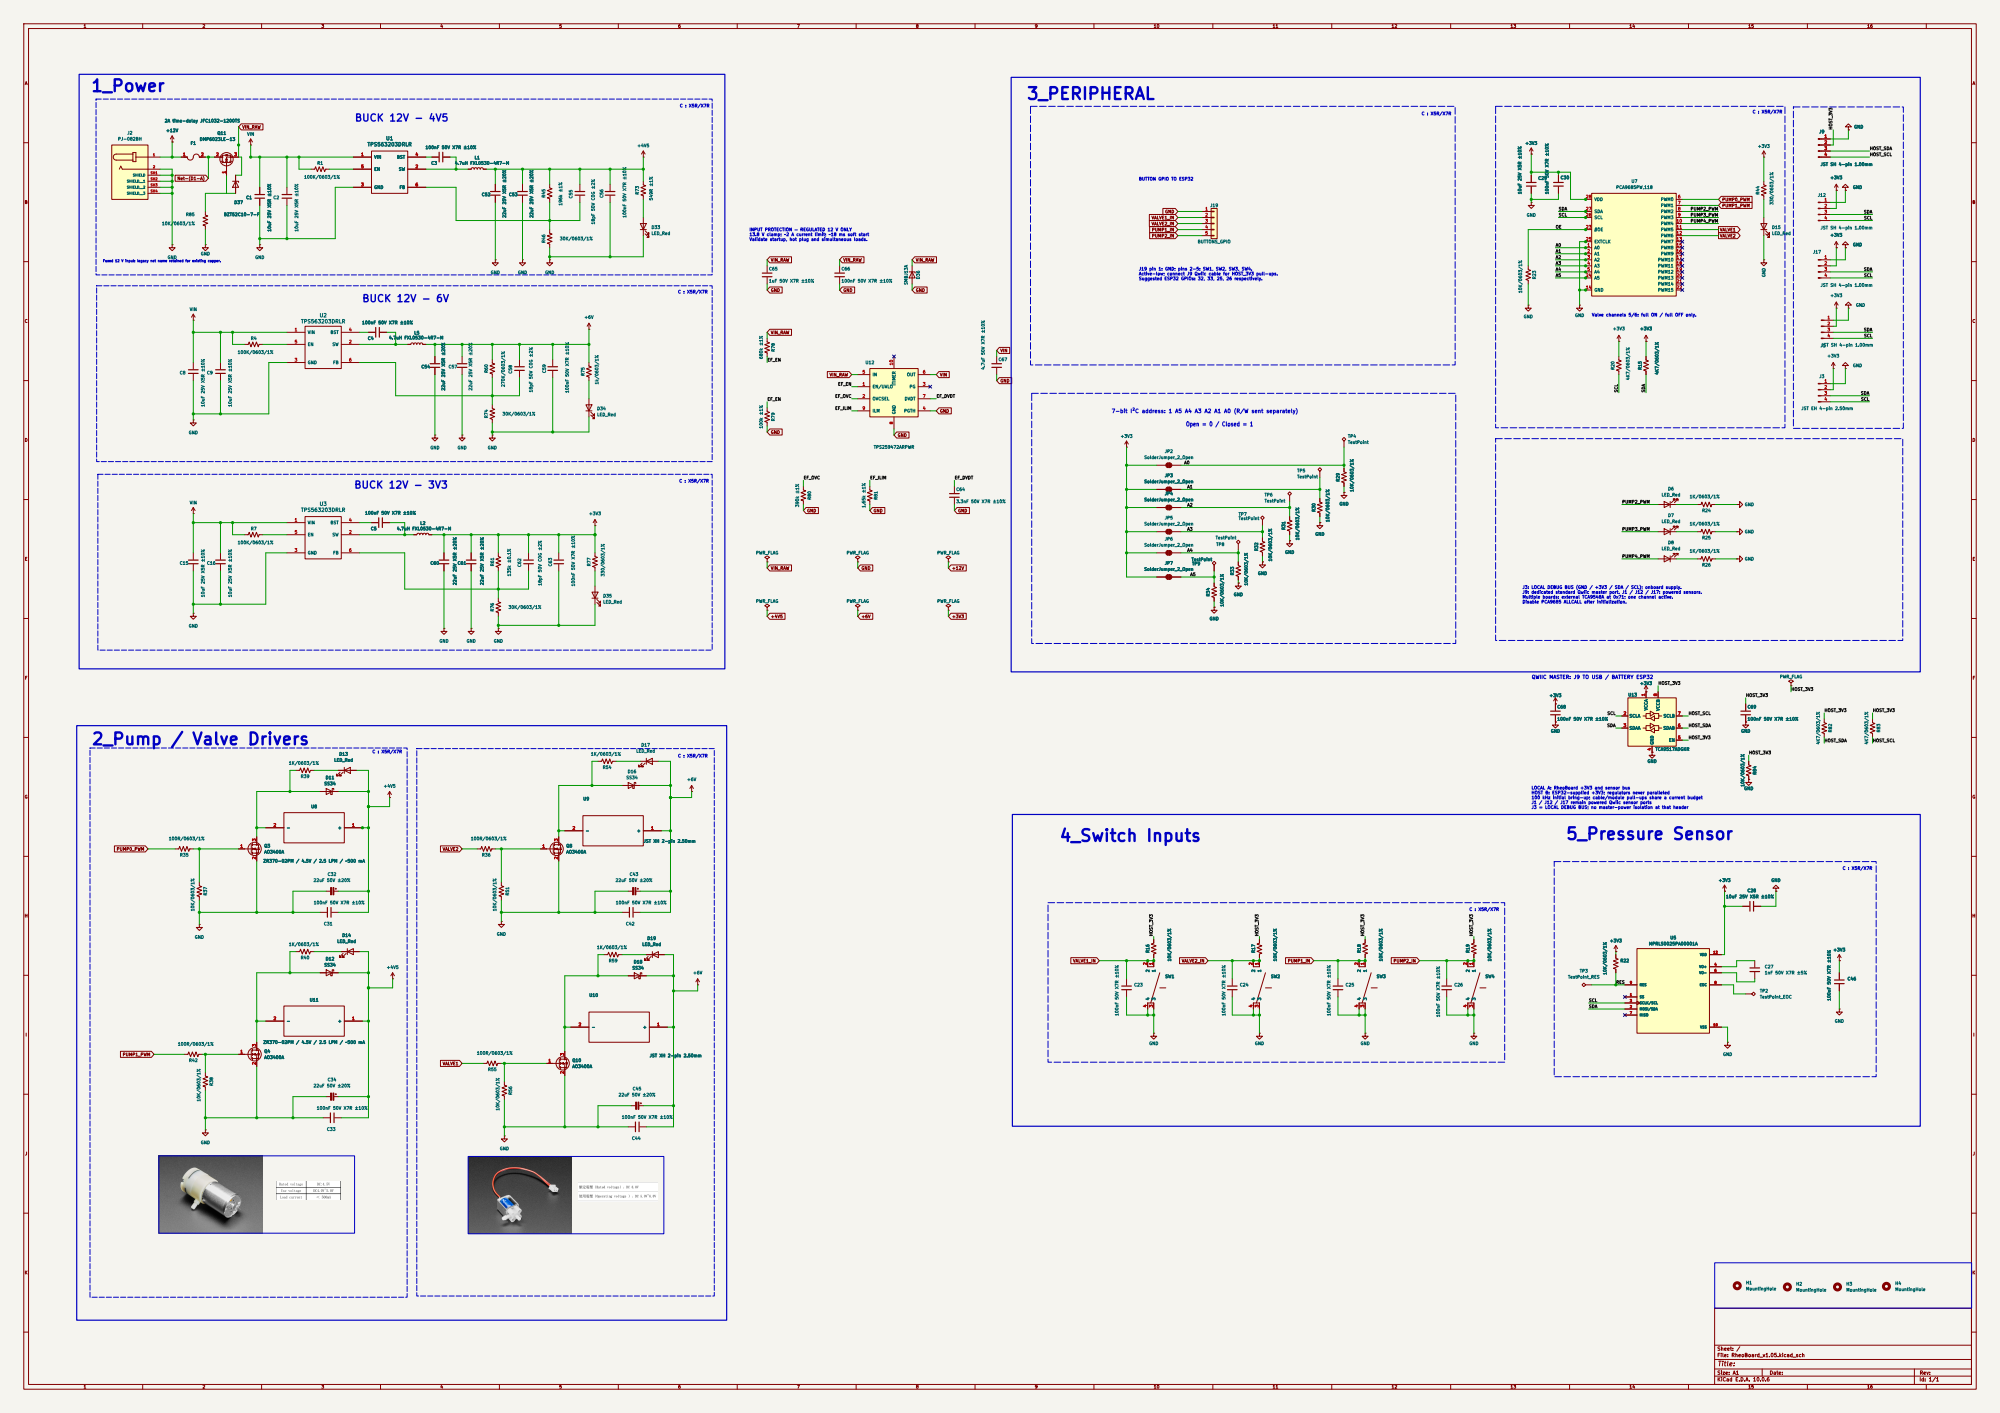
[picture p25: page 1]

BUTTON GPIO TO ESP32 2_Pump / Valve Drivers

SDA SCL SDA SCL SDA
SCL OE

Fused 12 V input: legacy net name retained for existing copper.

J19 pin 1: GND; pins 2-5: SW1, SW2, SW3, SW4. Active-low; connect J9 Qwiic cable for HOST_3V3 pull-ups.

7-bit I²C address: 1 A5 A4 A3 A2 A1 A0 (R/W sent separately) C : X5R/X7R

Valve channels 5/6: full ON / full OFF only.

J3: LOCAL DEBUG BUS (GND / +3V3 / SDA / SCL); onboard supply. J9: dedicated standard Qwiic master port. J1 / J12 / J17: powered sensors. Multiple boards: external TCA9548A at 0x71; one channel active. Disable PCA9685 ALLCALL after initialization. C : X5R/X7R

QWIIC MASTER: J9 TO USB / BATTERY ESP32

LOCAL A: RheoBoard +3V3 and sensor bus HOST B: ESP32-supplied +3V3; regulators never paralleled 100 kHz initial bring-up; cable/module pull-ups share a current budget J1 / J12 / J17 remain powered Qwiic sensor ports

J3 = LOCAL DEBUG BUS; no master-power isolation at that header 5_Pressure Sensor

Size: A1 | Rev:
KiCad E.D.A. 10.0.6 | Id: 1/1

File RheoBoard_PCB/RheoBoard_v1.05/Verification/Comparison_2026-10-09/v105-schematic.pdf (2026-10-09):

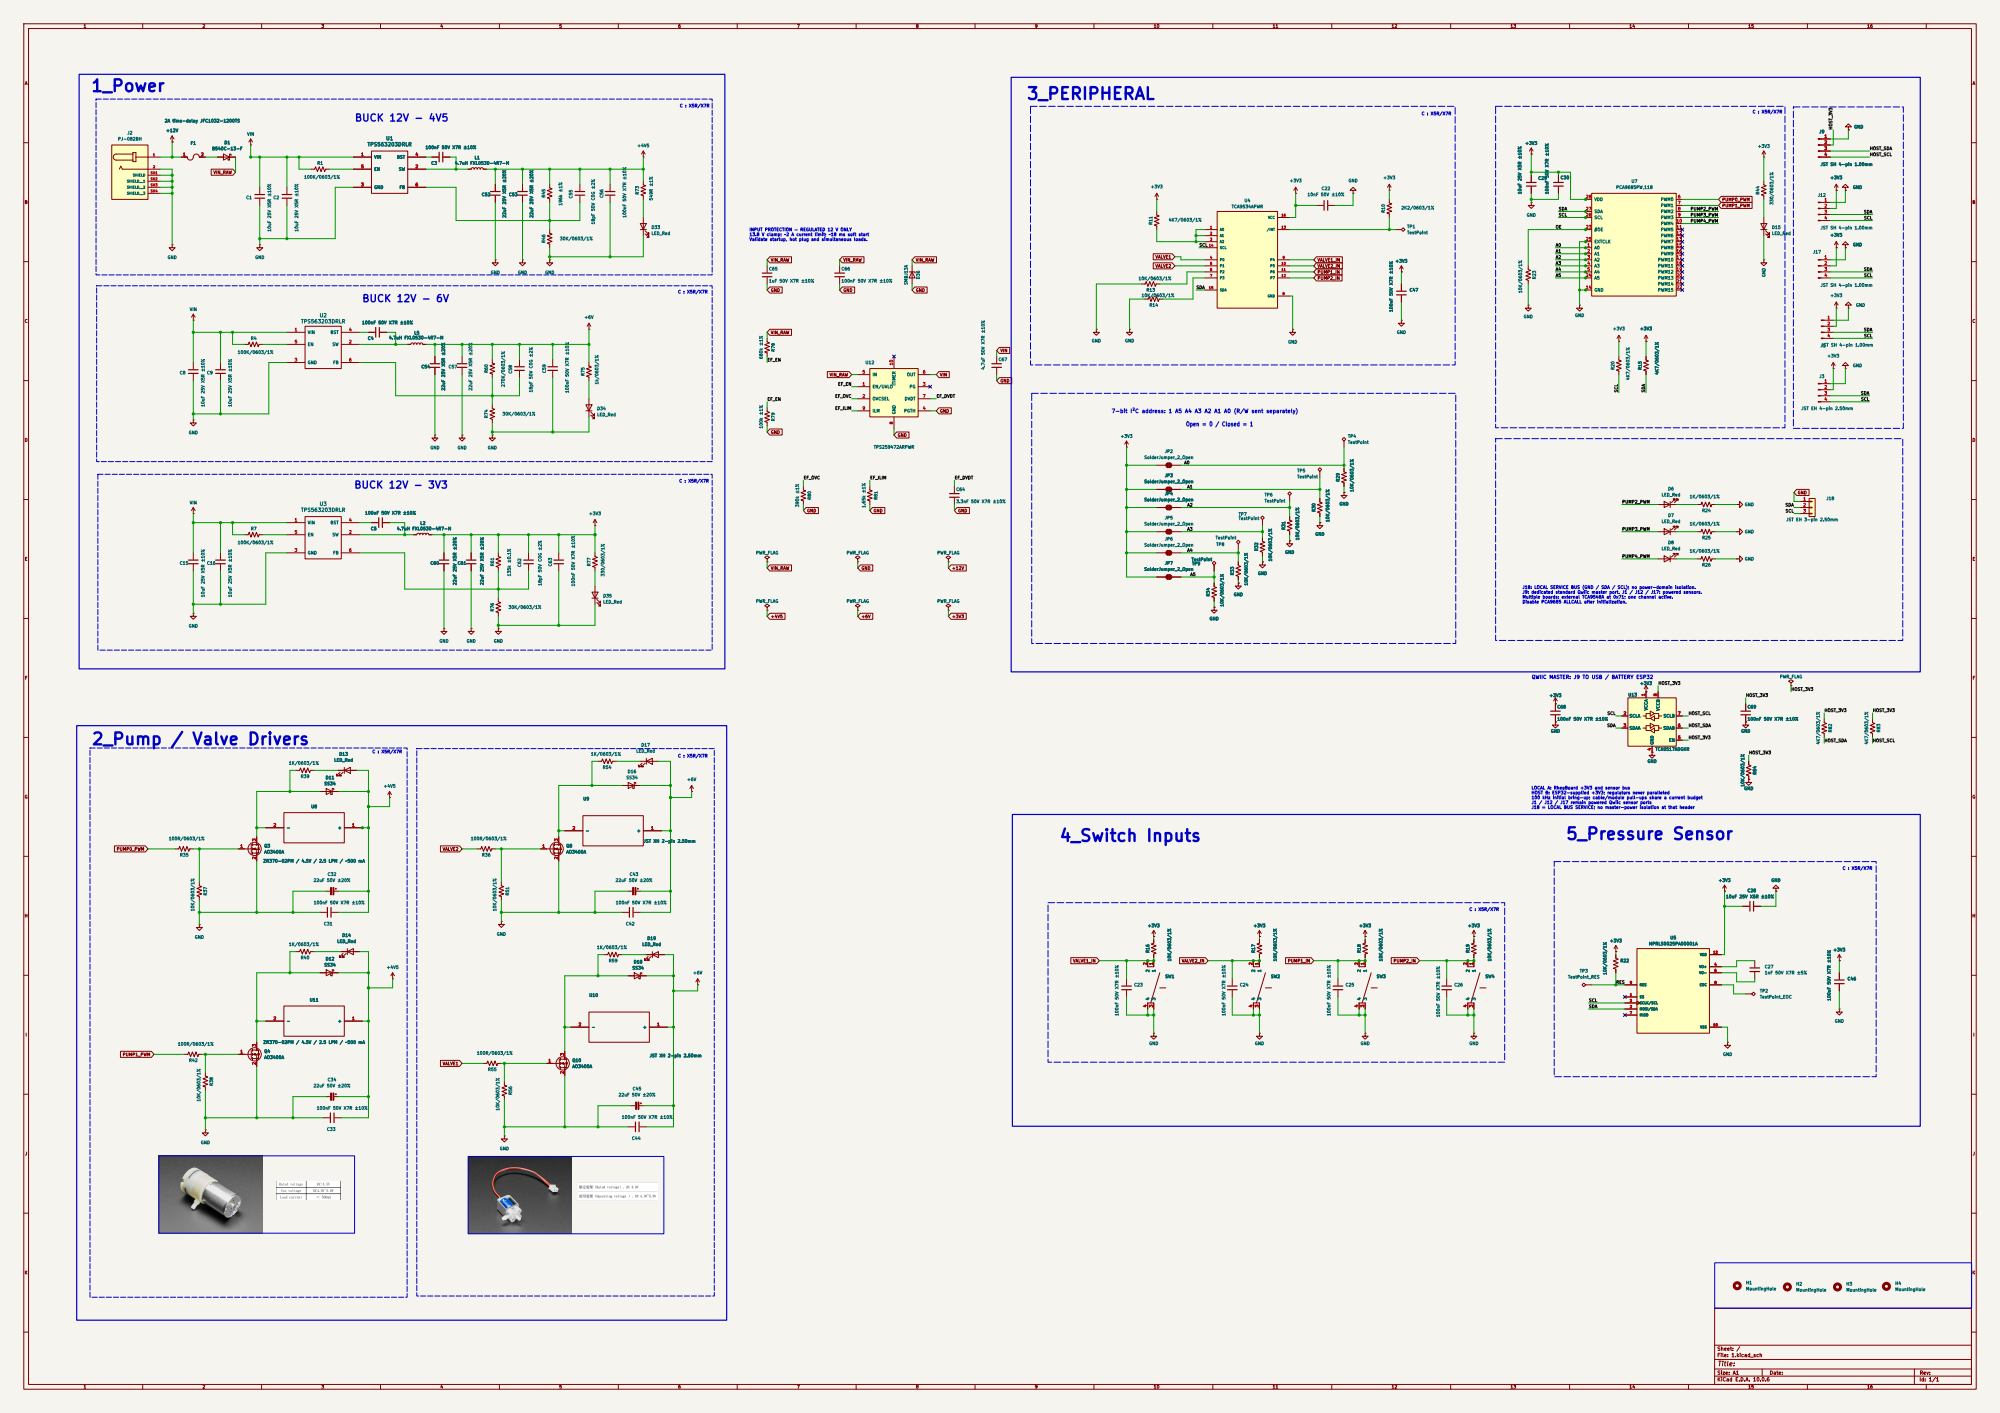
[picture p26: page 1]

HOST_SDA HOST_SCL SCL SDA SCL SDA SCL SDA SDA

J18: LOCAL SERVICE BUS (GND / SDA / SCL); no power-domain isolation. J9: dedicated standard Qwiic master port. J1 / J12 / J17: powered sensors. Multiple boards: external TCA9548A at 0x71; one channel active. Disable PCA9685 ALLCALL after initialization. 3_PERIPHERAL

INPUT PROTECTION — REGULATED 12 V ONLY 13.8 V clamp; ~2 A current limit; ~18 ms soft start Validate startup, hot plug and simultaneous loads. BUCK 12V - 4V5

QWIIC MASTER: J9 TO USB / BATTERY ESP32

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

J18 = LOCAL BUS SERVICE; no master-power isolation at that header
5_Pressure Sensor

Size: A1 | Rev:
KiCad E.D.A. 10.0.6 | Id: 1/1

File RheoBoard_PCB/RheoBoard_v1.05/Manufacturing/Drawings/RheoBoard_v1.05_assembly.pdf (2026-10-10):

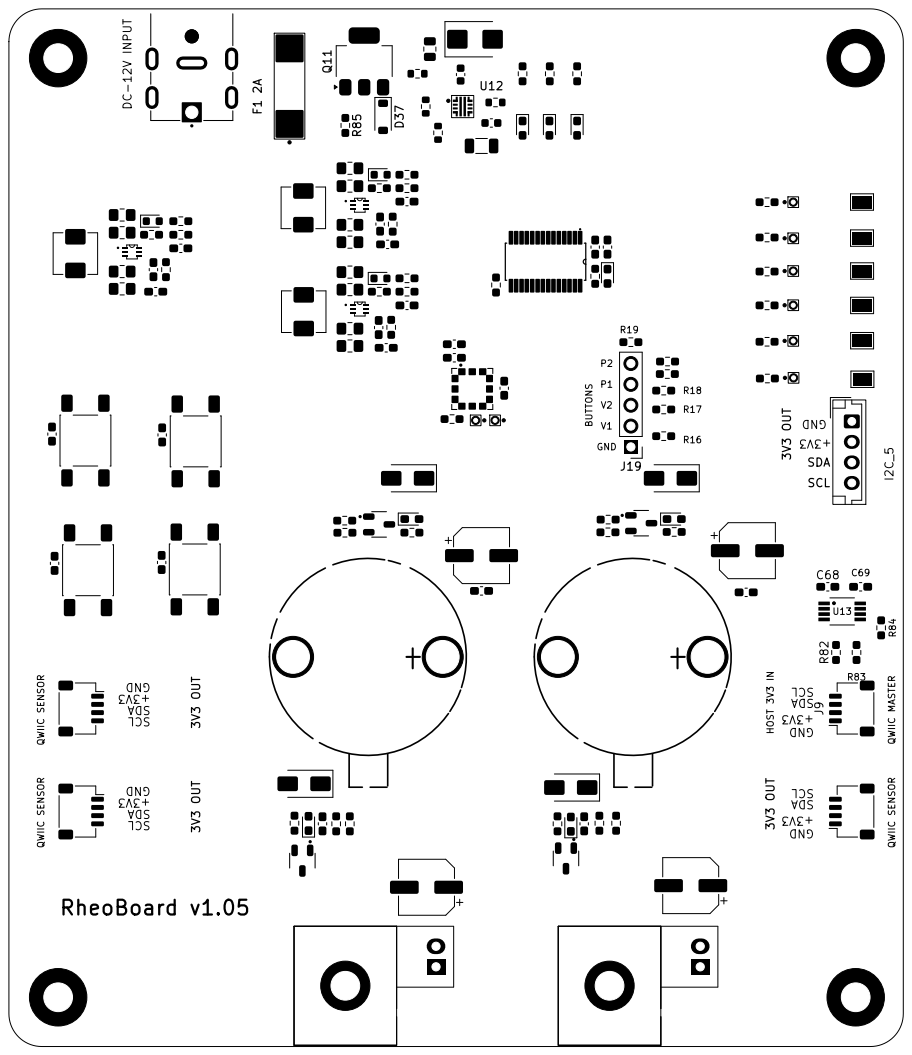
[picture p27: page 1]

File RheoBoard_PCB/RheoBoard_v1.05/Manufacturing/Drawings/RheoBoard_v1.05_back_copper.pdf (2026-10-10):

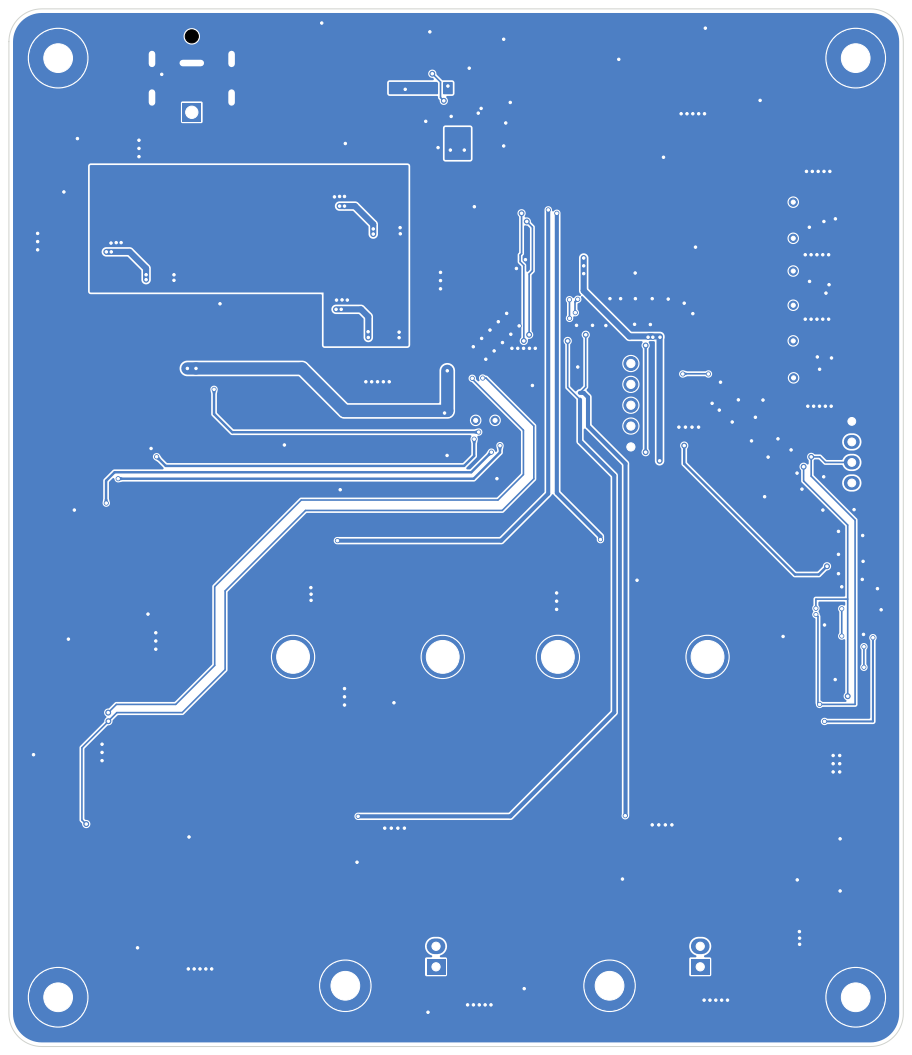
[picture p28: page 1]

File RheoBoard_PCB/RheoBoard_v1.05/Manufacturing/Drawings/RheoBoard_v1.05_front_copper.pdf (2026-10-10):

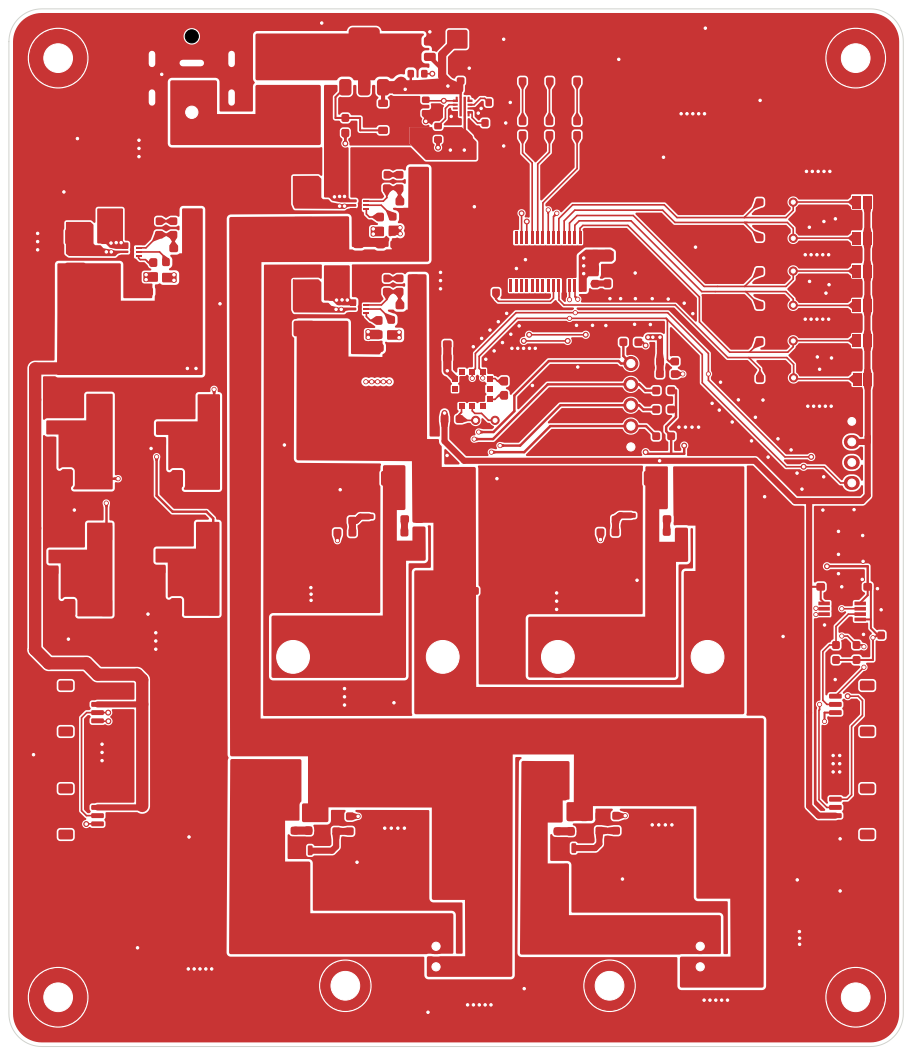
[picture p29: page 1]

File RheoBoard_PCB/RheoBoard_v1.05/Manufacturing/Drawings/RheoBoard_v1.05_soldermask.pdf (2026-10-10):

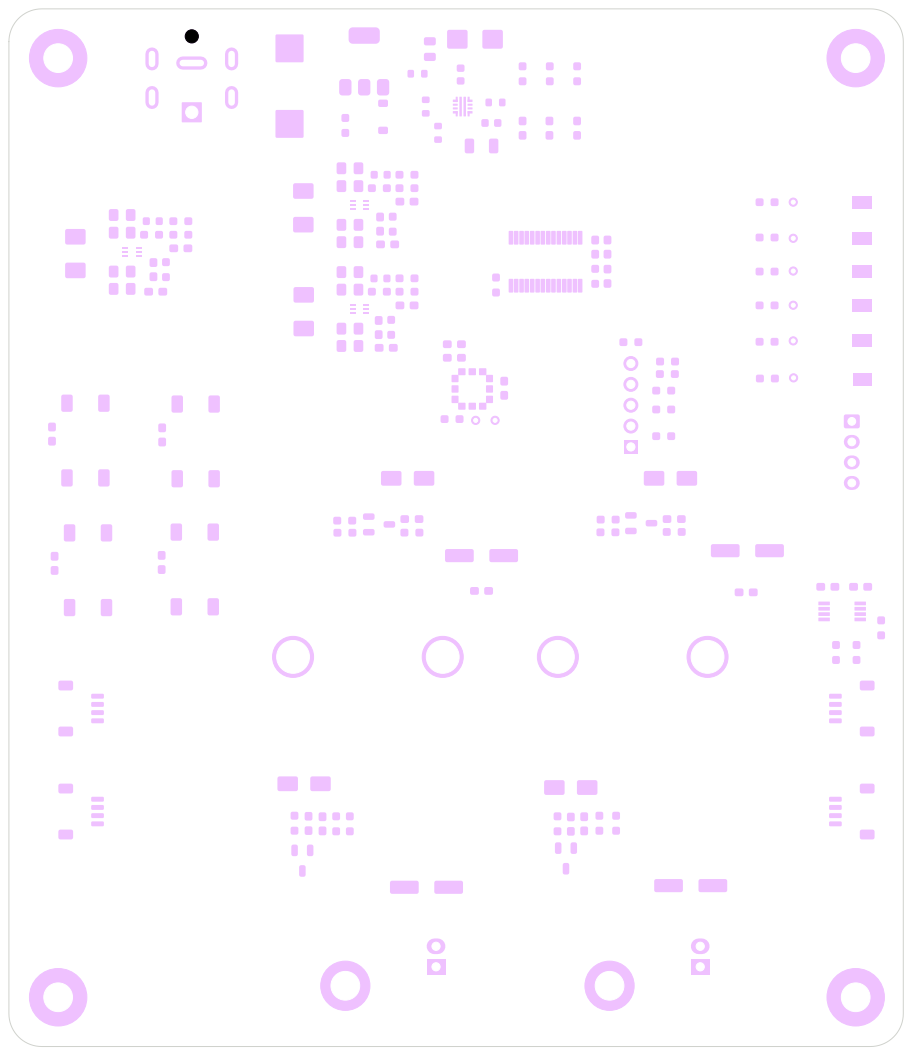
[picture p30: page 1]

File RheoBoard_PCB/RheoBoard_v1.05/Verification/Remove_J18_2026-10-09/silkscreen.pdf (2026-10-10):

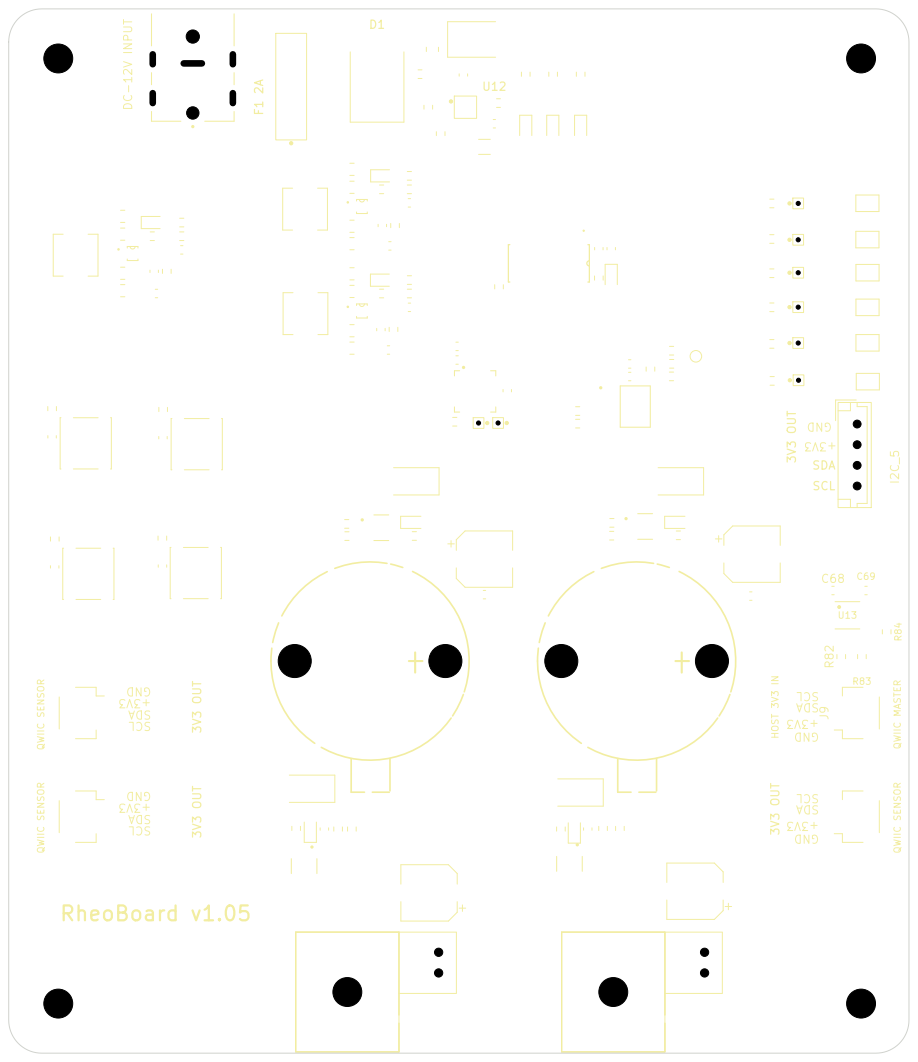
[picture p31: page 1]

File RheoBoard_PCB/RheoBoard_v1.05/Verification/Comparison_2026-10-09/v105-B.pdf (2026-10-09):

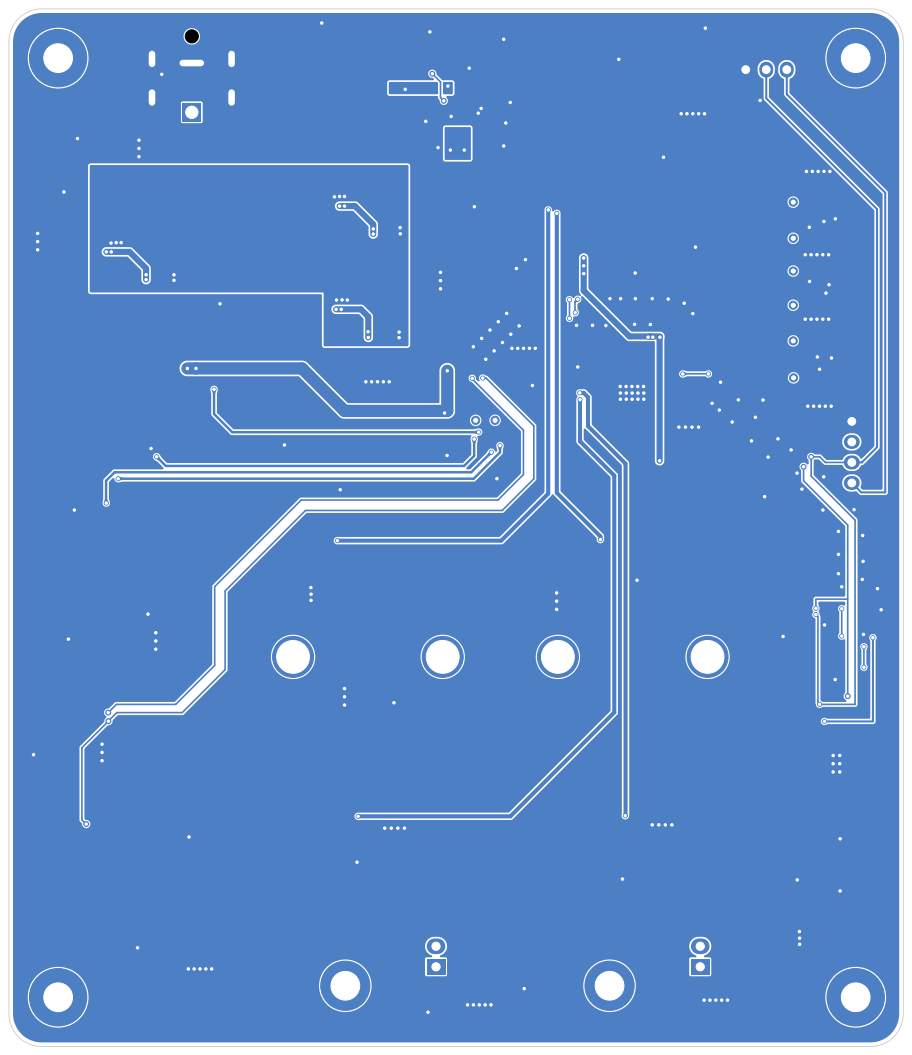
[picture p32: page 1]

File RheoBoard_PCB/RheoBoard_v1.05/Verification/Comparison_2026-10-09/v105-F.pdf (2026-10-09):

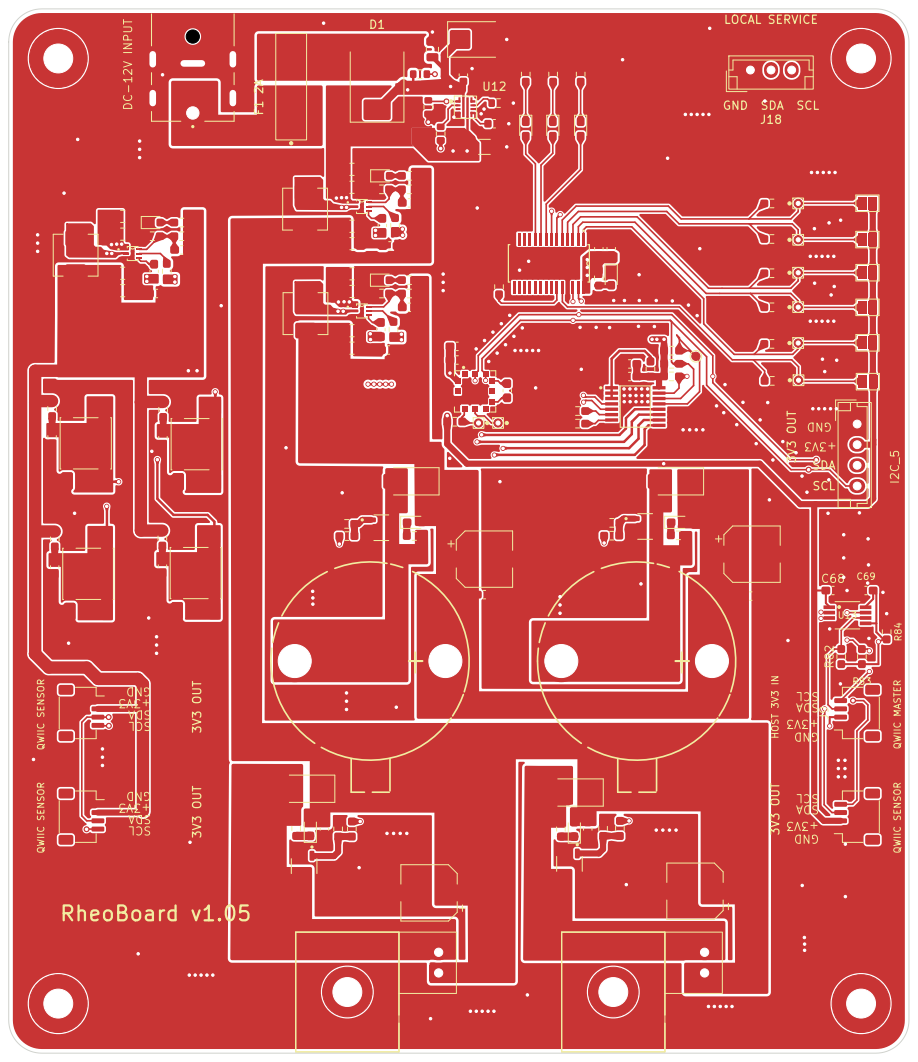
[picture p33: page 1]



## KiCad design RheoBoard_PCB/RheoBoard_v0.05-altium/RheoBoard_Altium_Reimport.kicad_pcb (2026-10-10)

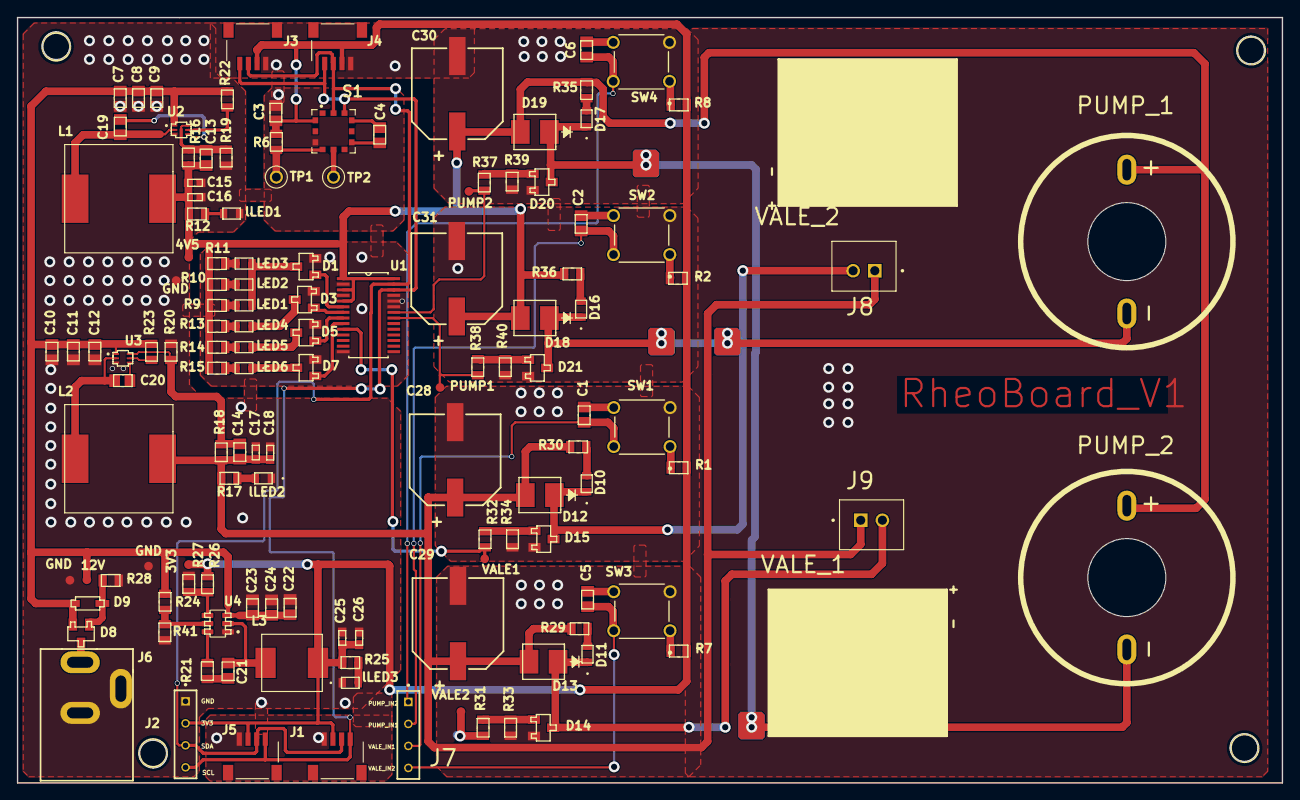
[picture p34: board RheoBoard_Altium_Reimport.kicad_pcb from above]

Board: 2 copper layers, 146.0 x 88.3 mm, 132 parts (0 on the bottom side), 71 nets.

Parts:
3V3, 4V5, 12V: TP_1MM; TP_1mm
C1, C2, C3, C5, C6, C9, C12, C19, C20, C21, C22: 0.1UF,50V; CAP_CER_0805
C4: 1nF 50V; CAP_CER_0805
C7, C8, C10, C11: 10UF 50V; CAP_CER_0805
C13, C14: 18pF 50V; CAP_CER_0805
C15, C16, C17, C18, C25, C26: 22uF 6.3V; CAP_CER_0603
C23, C24: 10UF 25V; CAP_CER_0805
C28, C29, C30, C31: 100uF 25V; CAP_ALUM_SMD_D10_H12.4
D1, D3, D5, D7, D14, D15, D20, D21: 30V 5.8A; SOT-23-3
D8: 20V 4A; SOT-23-3
D9: BZT52C5V1; SOD-123
D10, D11, D16, D17: Led green; LED_LS R976_AOS
D12, D13, D18, D19: 3A 40V; DO214AA
GND: TP_1MM; TP_1mm
GND#2, GND#3: TP_1MM; TP_1mm
J1, J3, J4, J5: 14417; SPARKFUN_PRT-14417
J2: TS-104-T-A; HDR_THT_1X04_P2.54
J6: 694106301002; CONN PWR JACK 2.1X5.5MM SOLDER
J7: TS-104-T-A; HDR_THT_1x04_P2.54
J8, J9: VERT; CONN_SMD_TOP_P2.50
L1, L2: 2.2uH; IND_12.5x12.5_H8.5
L3: 4.7uH; IND_6.8X6.5_H2.8
LED1, LED2, LED3: RED 2V 20mA; LED_LS R976_AOS
LED4, LED5, LED6: Led green; LED_LS R976_AOS
PUMP1, PUMP2: TP_1MM; TP_1mm
PUMP_1, PUMP_2: 0010844022; PUMP_LPM - ZR370-02PM
R1, R2, R6, R7, R8, R33, R34, R39, R40: 10K 1% 0805; RES_0805
R9, R10, R11, R13, R14, R15, R29, R30, R35, R36: 220R 0805; RES_0805
R12, R17: 1K 1% 0805; RES_0805
R16: 130K 0805; RES_0805
R18: 270K 0805; RES_0805
R19: 20K 0805; RES_0805
R20: 30K 0805; RES_0805
R21: 30Ohm 0805; RES_0805
R22, R23, R28: 100K 0805; RES_0805
R24: 174K 0805; RES_0805
R25: 470R 0805; RES_0805
R26: 75K 0805; RES_0805
R27: 24K 0805; RES_0805
R31, R32, R37, R38: 100R 0805; RES_0805
R41: 36.5K 0805; RES_0805
S1: MPRLS0025PA00001A; XDCR_MPRLS0025PA00001A
SW1, SW2, SW3, SW4: B3F-1020; SW_B3F-1000_OMR
TP1, TP2: 5002; KEYSTONE_5002
U1: PCA9685PW,118; TSSOP-28
U2, U3: TPS563203DRLR; SOT-563
U4: TPS56339DDCT; SOT-23-6
VALE1, VALE2: TP_1MM; TP_1mm
VALE_1, VALE_2: 0010844022; VALE_FA0520E
lLED1, lLED2, lLED3: RED 2V 20mA; LED_LS R976_AOS

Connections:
+12: 12V.1, C7.2, C8.2, C9.2, C10.2, C11.2, C12.2, C22.2, C23.2, C24.2, D8.2, D9.1, R22.2, R23.2, R24.2, U2.1, U3.1, U4.3
GND: C3.2, C7.1, C8.1, C9.1, C10.1, C11.1, C12.1, C15.1, C16.1, C17.1, C18.1, C22.1, C23.1, C24.1, C25.1, C26.1, C28.2, C29.2, C30.2, C31.2, D1.2, D3.2, D5.2, D7.2, D14.2, D15.2, D20.2, D21.2, GND.1, GND#2.1, GND#3.1, J1.1, J2.01, J3.1, J4.1, J5.1, J6.2, J6.3, R19.2, R20.1, R27.1, R28.1, R33.1, R34.1, R39.1, R40.1, R41.1, S1.10, SW1.3, SW2.3, SW3.3, SW4.3, U1.2, U1.4, U1.14, U1.23, U1.24, U1.25, U2.3, U3.3, U4.1, lLED1.1, lLED2.1, lLED3.1
Net3V3_1: 3V3.1, C3.1, C25.2, C26.2, J1.2, J2.02, J3.2, J4.2, J5.2, L3.2, R1.2, R2.2, R6.2, R7.2, R8.2, R25.2, R26.2, S1.12
Net4V5_1: 4V5.1, C13.2, C15.2, C16.2, C30.1, C31.1, D18.2, D19.2, L1.1, PUMP_1.1, PUMP_2.1, R9.2, R10.2, R11.2, R12.2, R13.1, R14.1, R15.1, R16.2, R35.1, R36.1, U1.1, U1.3, U1.5, U1.28
NetC1_1: C1.1, SW1.4
NetC2_1: C2.1, SW2.4
NetC4_1: C4.1, S1.6
NetC4_2: C4.2, S1.4
NetC5_1: C5.1, SW3.4
NetC6_1: C6.1, SW4.4
NetC13_1: C13.1, R16.1, R19.1, U2.6
NetC14_1: C14.1, R18.1, R20.2, U3.6
NetC14_2: C14.2, C17.2, C18.2, C28.1, C29.1, D12.2, D13.2, J8.1, J9.1, L2.1, R17.2, R18.2, R29.1, R30.1
NetC19_1: C19.1, L1.2, U2.2
NetC19_2: C19.2, U2.4
NetC20_1: C20.1, L2.2, U3.2
NetC20_2: C20.2, U3.4
NetC21_1: C21.1, L3.1, U4.2
NetC21_2: C21.2, R21.2
NetD1_1: D1.1, U1.6
NetD1_3: D1.3, LED1.1, LED2.1, LED3.1
NetD3_1: D3.1, U1.7
NetD3_3: D3.3, LED4.1
NetD5_1: D5.1, U1.8
NetD5_3: D5.3, LED5.1
NetD7_1: D7.1, U1.9
NetD7_3: D7.3, LED6.1
NetD8_1: D8.1, D9.2, R28.2
NetD8_3: D8.3, J6.1
NetD10_1: D10.1, D12.1, D15.3, J8.2
NetD10_2: D10.2, R30.2
NetD11_1: D11.1, D13.1, D14.3, J9.2
NetD11_2: D11.2, R29.2
NetD14_1: D14.1, R31.2, R33.2
NetD15_1: D15.1, R32.2, R34.2
NetD16_1: D16.1, D18.1, D21.3, PUMP_1.2
NetD16_2: D16.2, R36.2
NetD17_1: D17.1, D19.1, D20.3, PUMP_2.2
NetD17_2: D17.2, R35.2
NetD20_1: D20.1, R37.2, R39.2
NetD21_1: D21.1, R38.2, R40.2
NetLED1_2: LED1.2, R9.1
NetLED2_2: LED2.2, R10.1
NetLED3_2: LED3.2, R11.1
NetLED4_2: LED4.2, R13.2
NetLED5_2: LED5.2, R14.2
NetLED6_2: LED6.2, R15.2
NetPUMP1_1: PUMP1.1, R38.1, U1.21
NetPUMP2_1: PUMP2.1, R37.1, U1.22
NetR1_1: R1.1, SW1.1
NetR2_1: R2.1, SW2.1
NetR6_1: R6.1, S1.9, TP1.TP
NetR7_1: R7.1, SW3.1
NetR8_1: R8.1, SW4.1
NetR21_1: R21.1, U4.6
NetR22_1: R22.1, U2.5
NetR23_1: R23.1, U3.5
NetR24_1: R24.1, R41.2, U4.5
NetR26_1: R26.1, R27.2, U4.4
NetR31_1: R31.1, VALE2.1
NetR32_1: R32.1, U1.10, VALE1.1
NetS1_8: S1.8, TP2.TP
NetlLED1_2: R12.1, lLED1.2
NetlLED2_2: R17.1, lLED2.2
NetlLED3_2: R25.1, lLED3.2
PUMP1_IN: C2.2, J7.02, SW2.2
PUMP2_IN: C6.2, J7.01, SW4.2
SCL: J1.4, J2.04, J3.4, J4.4, J5.4, S1.3, U1.26
SDA: J1.3, J2.03, J3.3, J4.3, J5.3, S1.2, U1.27
VALE1_IN: C1.2, J7.03, SW1.2
VALE2_IN: C5.2, J7.04, SW3.2

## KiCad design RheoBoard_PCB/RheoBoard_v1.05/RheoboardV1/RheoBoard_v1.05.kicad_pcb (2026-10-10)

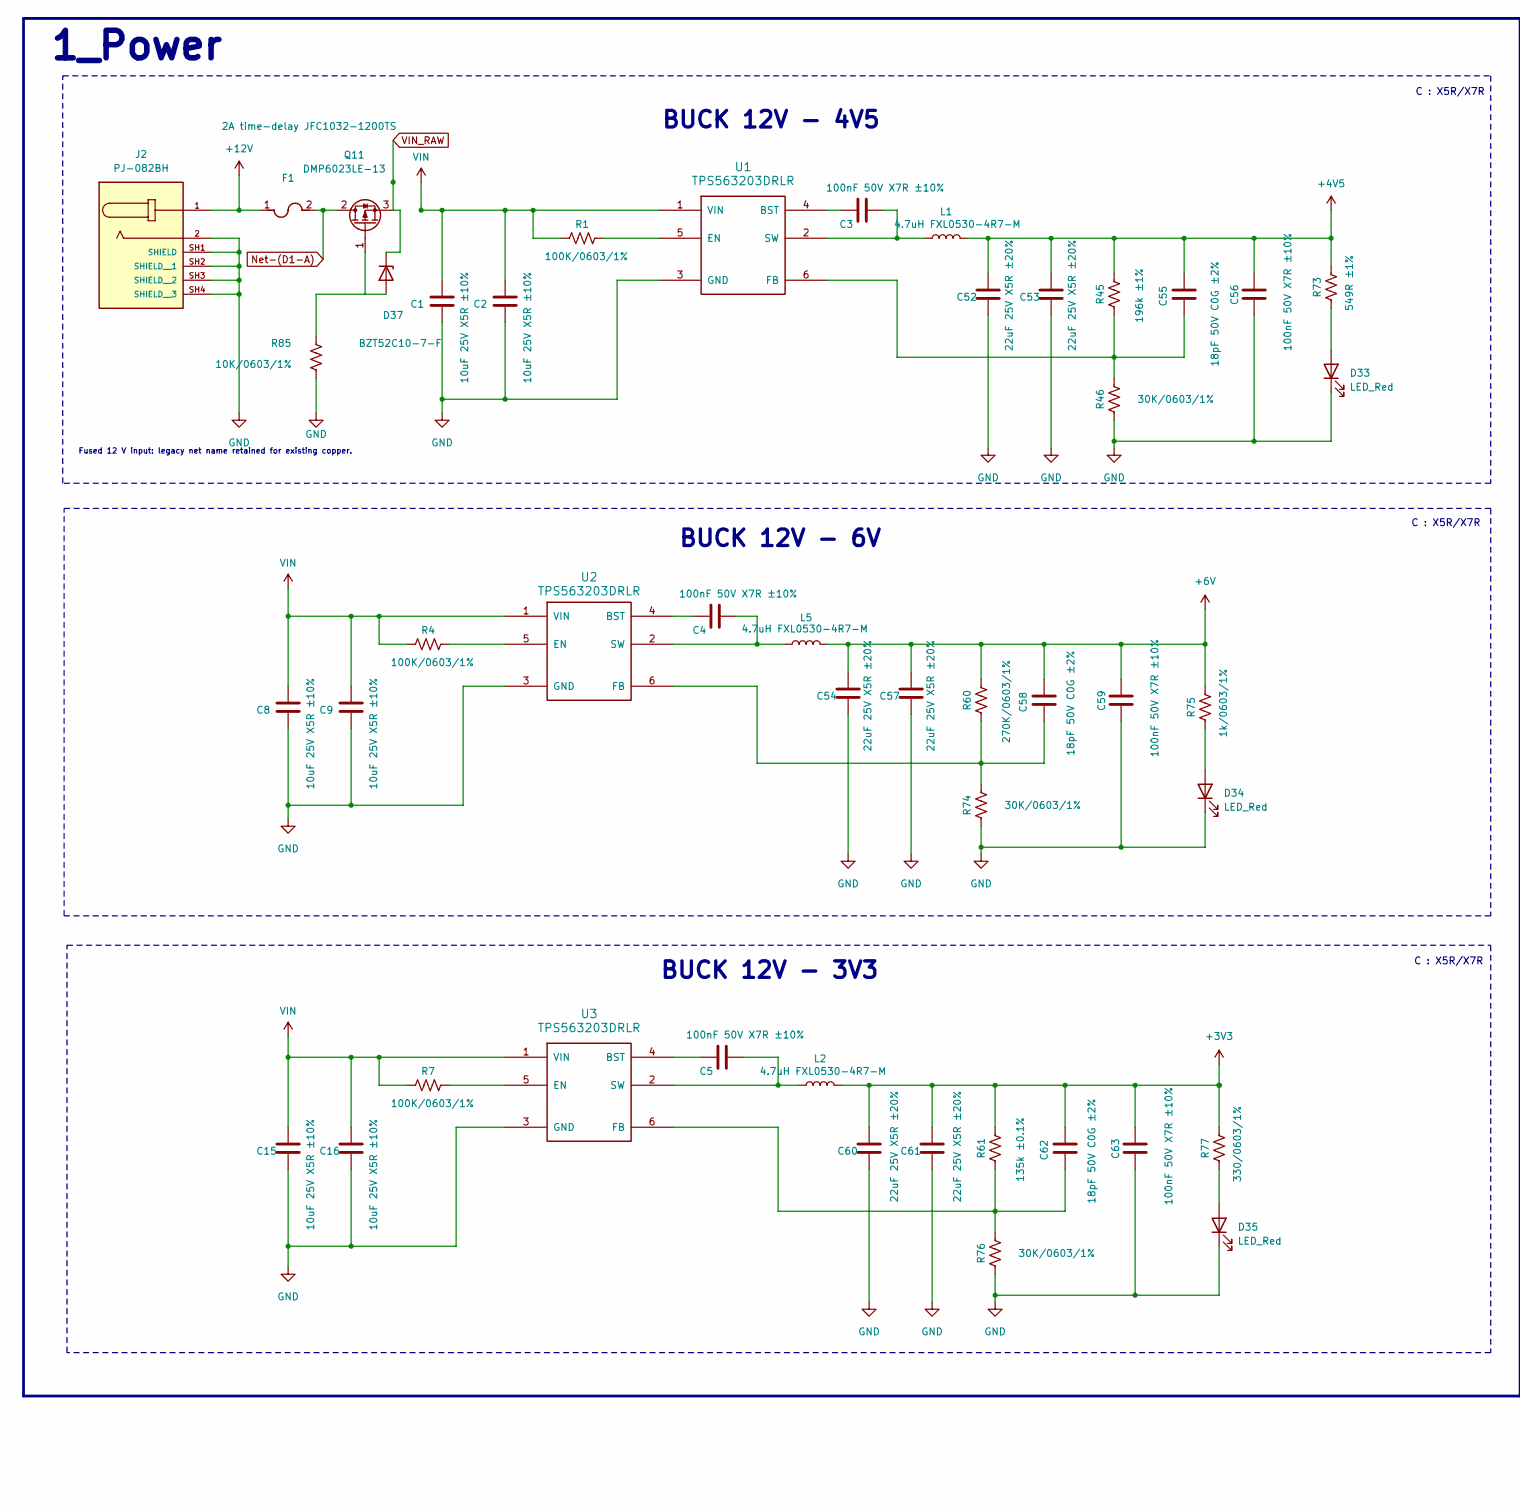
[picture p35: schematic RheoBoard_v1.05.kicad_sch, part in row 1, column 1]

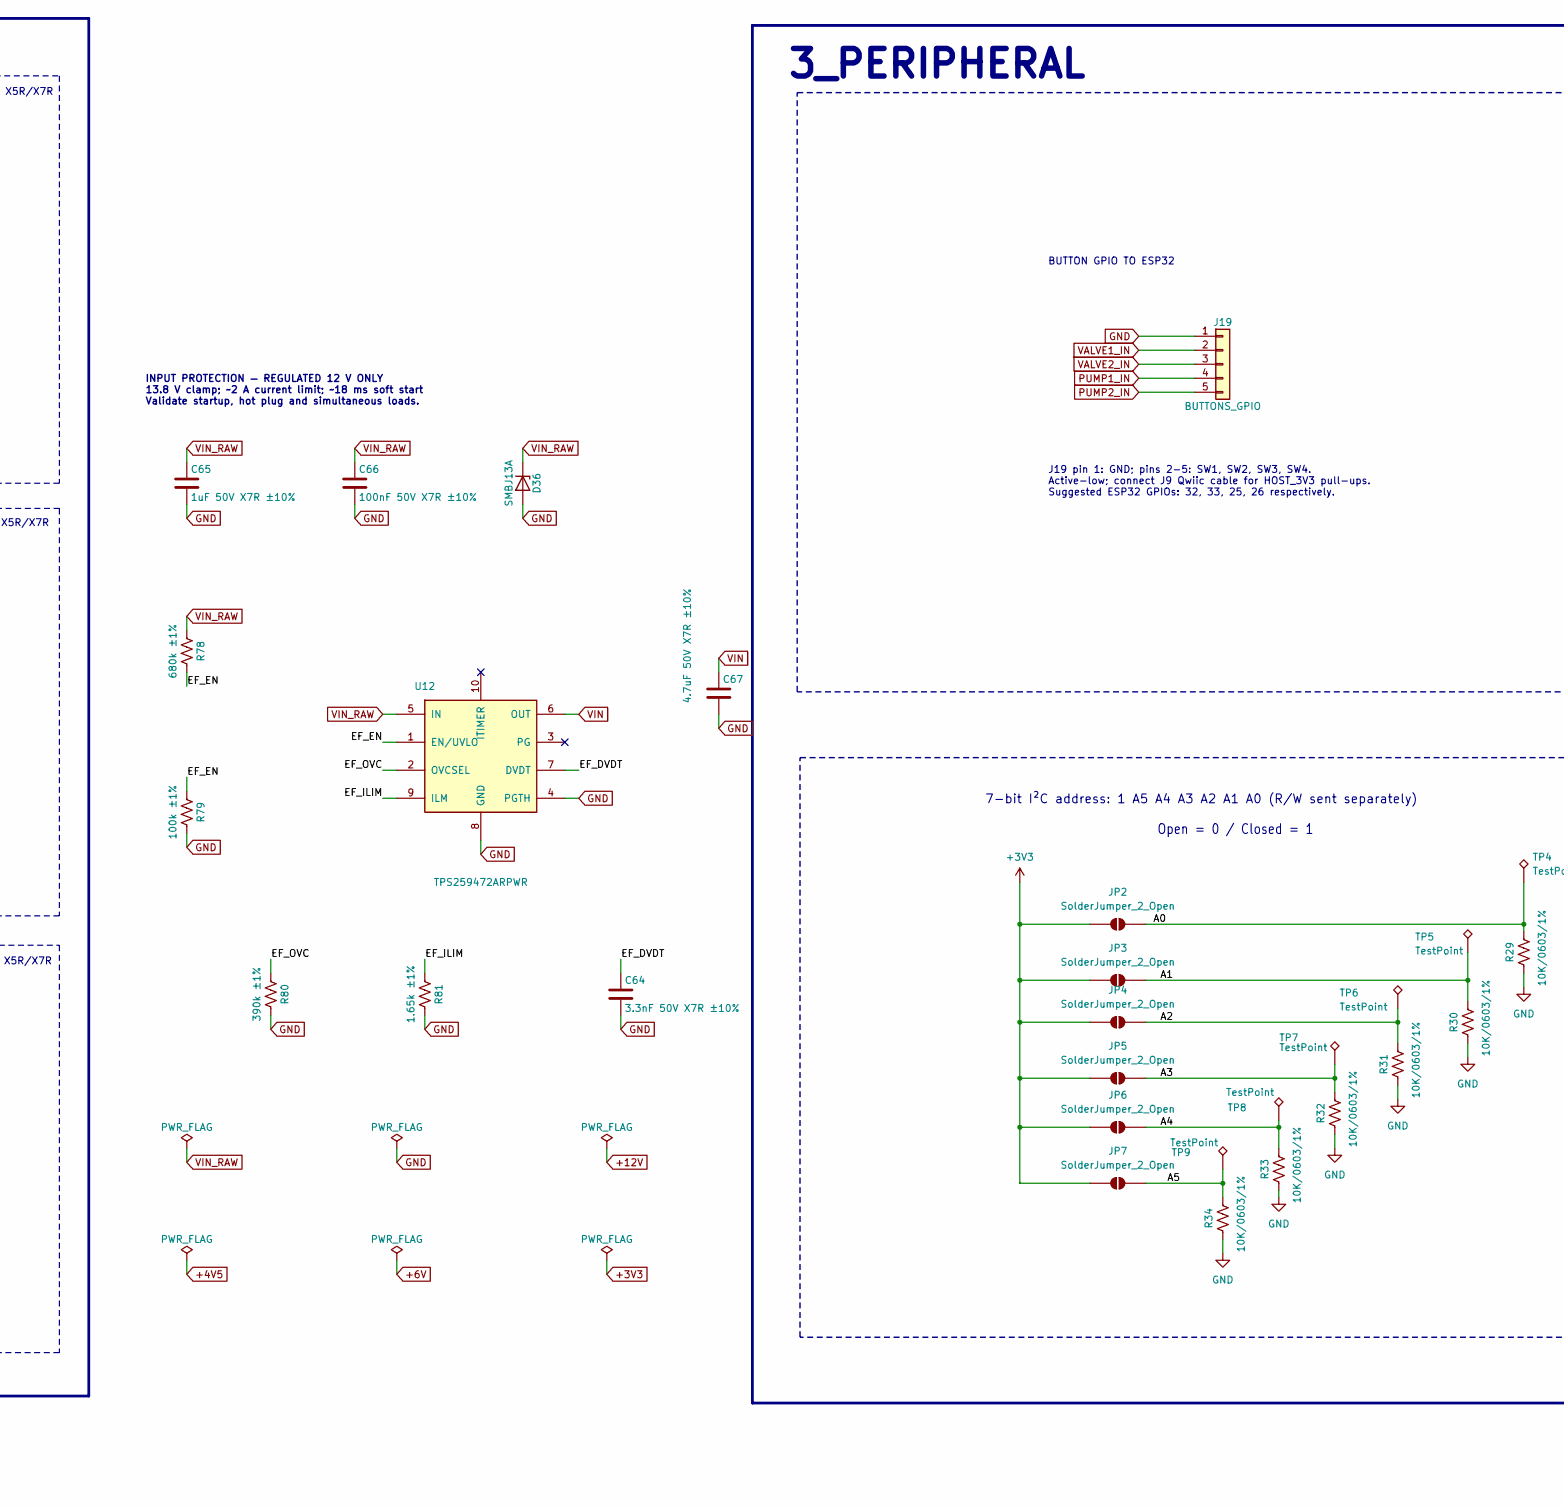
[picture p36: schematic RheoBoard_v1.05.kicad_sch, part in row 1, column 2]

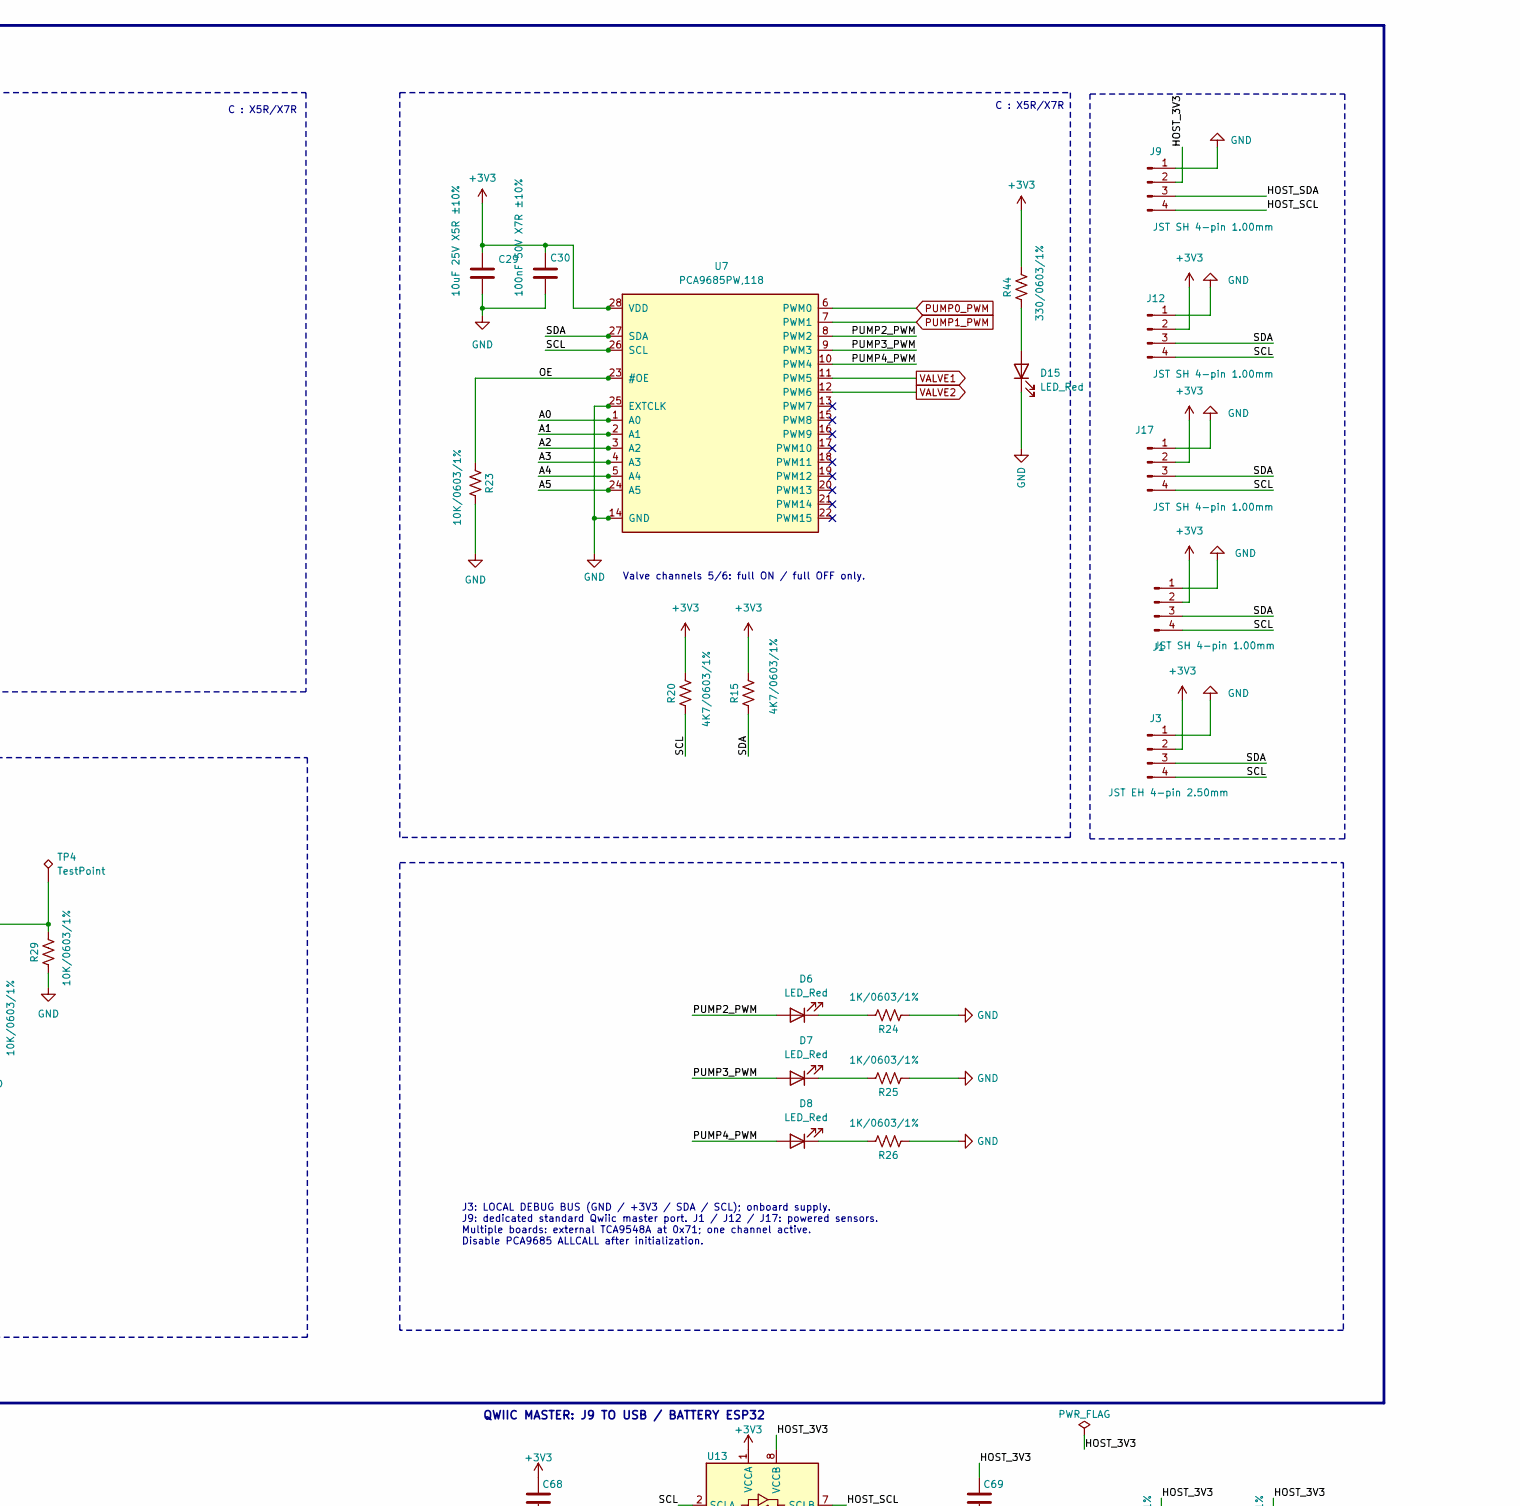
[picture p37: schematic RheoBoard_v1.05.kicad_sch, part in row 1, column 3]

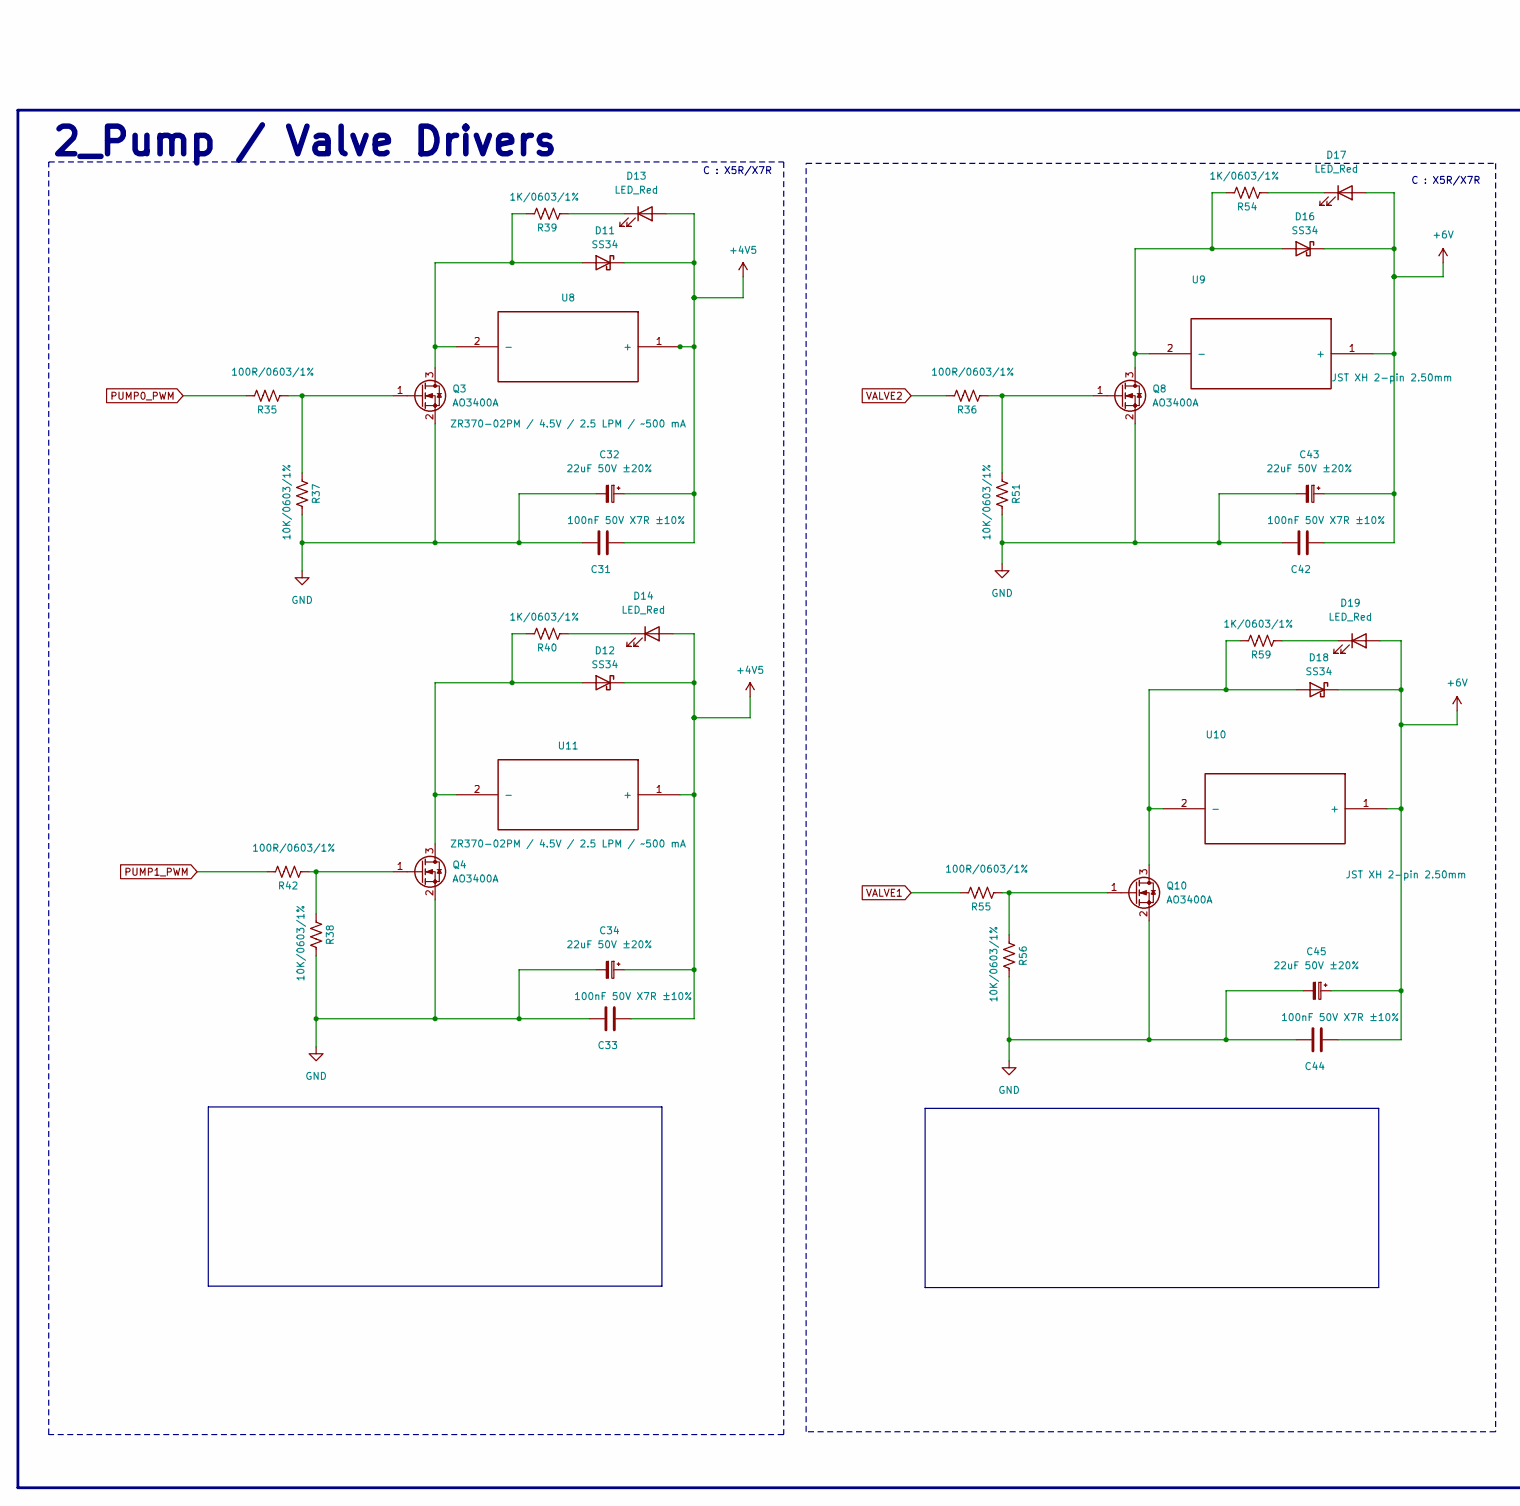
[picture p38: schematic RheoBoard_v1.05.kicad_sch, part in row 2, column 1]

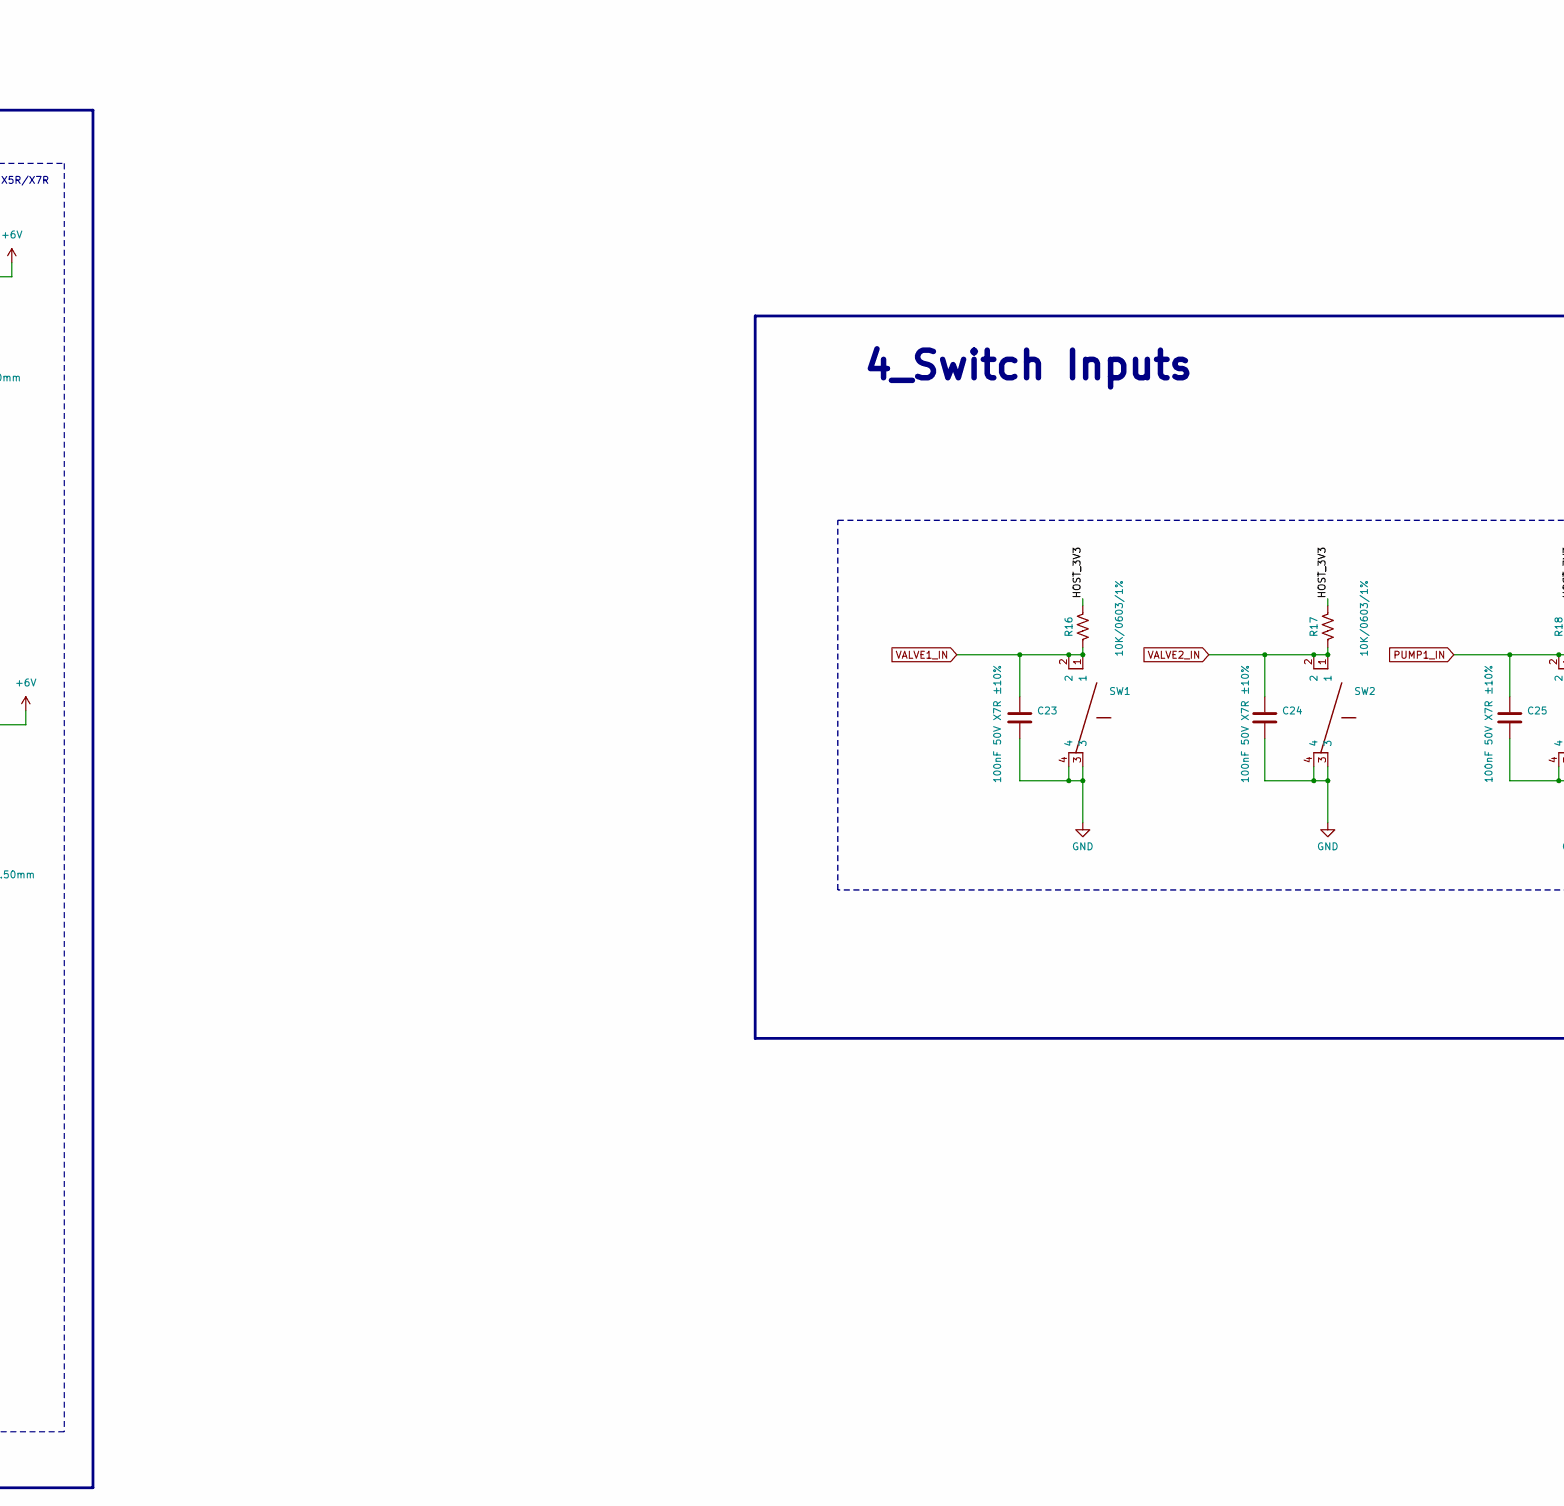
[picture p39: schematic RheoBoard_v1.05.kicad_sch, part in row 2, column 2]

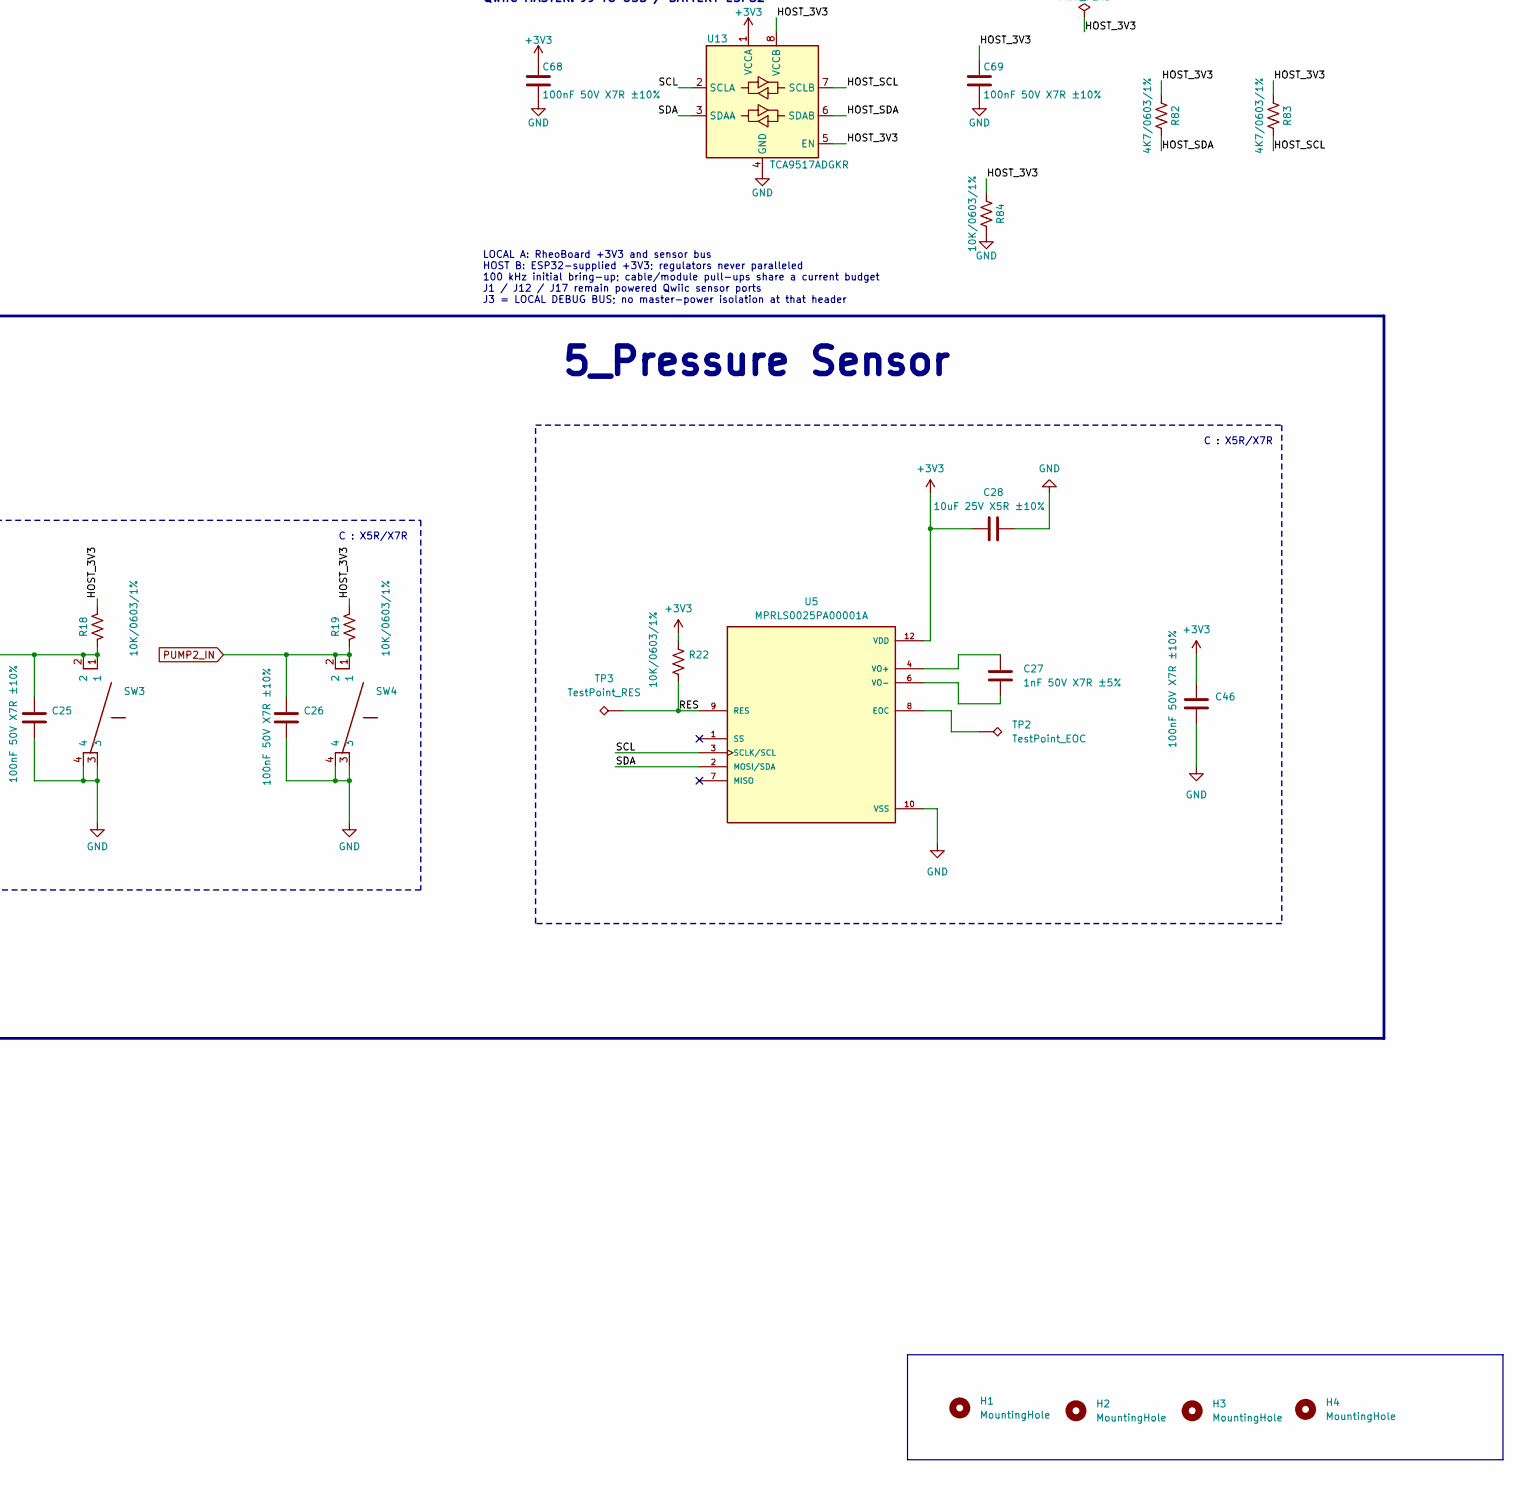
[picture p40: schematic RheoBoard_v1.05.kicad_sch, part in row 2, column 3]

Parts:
C1, C2, C8, C9, C15, C16: 10uF 25V X5R ±10%; C_0805_2012Metric_Pad1.18x1.45mm_HandSolder; MPN TCC0805X5R106K250FT; LCSC C5448891
C3, C4, C5, C23, C24, C25, C26, C30, C31, C33, C42, C44, C46, C56, C59, C63, C68, C69: 100nF 50V X7R ±10%; C_0603_1608Metric_Pad1.08x0.95mm_HandSolder; MPN CC0603KRX7R9BB104; LCSC C14663
C27: 1nF 50V X7R ±5%; C_0603_1608Metric_Pad1.08x0.95mm_HandSolder; MPN TCC0603X7R102J500CT; LCSC C5360811
C28, C29: 10uF 25V X5R ±10%; C_0603_1608Metric_Pad1.08x0.95mm_HandSolder; MPN TCC0603X5R106K250CT; LCSC C7393892
C32, C34, C43, C45: 22uF 50V ±20%; CP_Elec_6.3x5.8; MPN EEEFK1H220P; LCSC C128458
C52, C53, C54, C57, C60, C61: 22uF 25V X5R ±20%; C_0805_2012Metric_Pad1.18x1.45mm_HandSolder; MPN TCC0805X5R226M250FT; LCSC C20416420
C55, C58, C62: 18pF 50V C0G ±2%; C_0603_1608Metric_Pad1.08x0.95mm_HandSolder; MPN VJ0603A180GXACW1BC; LCSC C2169079
C64: 3.3nF 50V X7R ±10%; C_0603_1608Metric; MPN CC0603KRX7R9BB332; LCSC C107088
C65: 1uF 50V X7R ±10%; C_0805_2012Metric; MPN CC0805KKX7R9BB105; LCSC C91185
C66: 100nF 50V X7R ±10%; C_0603_1608Metric; MPN CC0603KRX7R9BB104; LCSC C14663
C67: 4.7uF 50V X7R ±10%; C_1206_3216Metric; MPN CC1206KKX7R9BB475; LCSC C132170
D6, D7, D8, D13, D14, D15, D17, D19: LED_Red; LED_0603_1608Metric_Pad1.05x0.95mm_HandSolder; MPN SZYY0603R; LCSC C434419
D11, D12, D16, D18: SS34; D_SMA; MPN SS34; LCSC C115205
D33, D34, D35: LED_Red; LED_0603_1608Metric; MPN SZYY0603R; LCSC C434419
D36: SMBJ13A; D_SMB; MPN SMBJ13A; LCSC C151252
D37: BZT52C10-7-F; D_SOD-123; MPN BZT52C10-7-F; LCSC C155227
F1: 2A time-delay JFC1032-1200TS; Fuse_JDT_JFC1032TS_10.25x3.2mm; MPN JFC1032-1200TS; LCSC C53035082
H1, H2, H3, H4: MountingHole; MountingHole_3.5mm_Pad
J1, J9, J12, J17: JST SH 4-pin 1.00mm; JST_SH_SM04B-SRSS-TB_1x04-1MP_P1.00mm_Horizontal; MPN SM04B-SRSS-TB(LF)(SN); LCSC C160404
J2: PJ-082BH; PARTREV 1.06; LCSC C3094233
J3: JST EH 4-pin 2.50mm; JST_EH_B4B-EH-A_1x04_P2.50mm_Vertical; MPN B4B-EH-A(LF)(SN); LCSC C160258
J19: BUTTONS_GPIO; PinHeader_1x05_P2.54mm_Vertical; MPN 1x05_2.54mm_vertical_header
JP2, JP3, JP4, JP5, JP6, JP7: SolderJumper_2_Open; SolderJumper-2_P1.3mm_Open_Pad1.0x1.5mm
L1, L2, L5: 4.7uH FXL0530-4R7-M; L_Changjiang_FXL0530; MPN FXL0530-4R7-M; LCSC C177246
Q3, Q4, Q8, Q10: AO3400A; MPN AO3400A; LCSC C20917
Q11: DMP6023LE-13; SOT-223-3_TabPin2; MPN DMP6023LE-13; LCSC C154901
R1, R4, R7: 100K/0603/1%; R_0603_1608Metric_Pad0.98x0.95mm_HandSolder; MPN 0603WAF1003T5E; LCSC C25803
R15, R20, R82, R83: 4K7/0603/1%; R_0603_1608Metric_Pad0.98x0.95mm_HandSolder; MPN 0603WAF4701T5E; LCSC C23162
R16, R17, R18, R19, R22, R23, R29, R30, R31, R32, R33, R34, R37, R38, R51, R56, R84, R85: 10K/0603/1%; R_0603_1608Metric_Pad0.98x0.95mm_HandSolder; MPN 0603WAF1002T5E; LCSC C25804
R24, R25, R26, R39, R40, R54, R59: 1K/0603/1%; R_0603_1608Metric_Pad0.98x0.95mm_HandSolder; MPN 0603WAF1001T5E; LCSC C21190
R35, R36, R42, R55: 100R/0603/1%; R_0603_1608Metric_Pad0.98x0.95mm_HandSolder; MPN 0603WAF1000T5E; LCSC C22775
R44, R77: 330/0603/1%; R_0603_1608Metric_Pad0.98x0.95mm_HandSolder; MPN 0603WAF3300T5E; LCSC C23138
R45: 196k ±1%; R_0603_1608Metric_Pad0.98x0.95mm_HandSolder; MPN CRCW0603196KFKEA; LCSC C4203218
R46, R74, R76: 30K/0603/1%; R_0603_1608Metric_Pad0.98x0.95mm_HandSolder; MPN 0603WAF3002T5E; LCSC C22984
R60: 270K/0603/1%; R_0603_1608Metric_Pad0.98x0.95mm_HandSolder; MPN 0603WAF2703T5E; LCSC C22965
R61: 135k ±0.1%; R_0603_1608Metric_Pad0.98x0.95mm_HandSolder; MPN RT0603BRD07135KL; LCSC C861113
R73: 549R ±1%; R_0603_1608Metric_Pad0.98x0.95mm_HandSolder; MPN 0603WAF5490T5E; LCSC C23079
R75: 1k/0603/1%; R_0603_1608Metric_Pad0.98x0.95mm_HandSolder; MPN 0603WAF1001T5E; LCSC C21190
R78: 680k ±1%; R_0603_1608Metric; MPN 0603WAF6803T5E; LCSC C25822
R79: 100k ±1%; R_0603_1608Metric; MPN 0603WAF1003T5E; LCSC C25803
R80: 390k ±1%; R_0603_1608Metric; MPN HP03W5F3903T5E; LCSC C2759410
R81: 1.65k ±1%; R_0603_1608Metric; MPN 0603WAF1651T5E; LCSC C22845
SW1, SW2, SW3, SW4: TL3301NF160QG/P010515; Tactile_Switch_4pad; MPN TL3301NF160QG/P010515; LCSC C273527
TP2: TestPoint_EOC; TestPoint_Plated_D1.0_Drill0.5
TP3: TestPoint_RES; TestPoint_Plated_D1.0_Drill0.5
TP4, TP5, TP6, TP7, TP8, TP9: TestPoint; TestPoint_Plated_D1.0_Drill0.5
U1, U2, U3: TPS563203DRLR; MPN TPS563203DRLR; LCSC C22445512
U5: MPRLS0025PA00001A; PARTREV 03/18; LCSC C3257154
U7: PCA9685PW,118; PCA9685; MPN PCA9685PW,118; LCSC C2678753
U8, U11: ZR370-02PM / 4.5V / 2.5 LPM / ~500 mA; PUMP; MPN ZR370-02PM
U9, U10: JST XH 2-pin 2.50mm; VALVE_v105; MPN B2B-XH-A(LF)(SN); LCSC C158012
U12: TPS259472ARPWR; TI_RPW0010A_VQFN-HR_2x2mm; MPN TPS259472ARPWR; LCSC C3662789
U13: TCA9517ADGKR; TI_DGK0008A_VSSOP_3x3mm_P0.65mm; MPN TCA9517ADGKR; LCSC C201698

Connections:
+3V3: C28.1, C29.1, C30.1, C46.1, C60.1, C61.1, C62.1, C63.1, C68.1, J1.2, J3.2, J12.2, J17.2, JP2.1 (A), JP3.1 (A), JP4.1 (A), JP5.1 (A), JP6.1 (A), JP7.1 (A), L2.2, R15.2, R20.2, R22.1, R44.2, R61.2, R77.2, U5.12 (VDD), U7.28 (VDD), U13.1 (VCCA)
+4V5: C31.2, C32.1, C33.2, C34.1, C52.1, C53.1, C55.1, C56.1, D11.1 (K), D12.1 (K), D13.2 (A), D14.2 (A), L1.2, R45.2, R73.2, U8.1 (+), U11.1 (+)
+6V: C42.2, C43.1, C44.2, C45.1, C54.1, C57.1, C58.1, C59.1, D16.1 (K), D17.2 (A), D18.1 (K), D19.2 (A), L5.2, R60.2, R75.2, U9.1 (+), U10.1 (+)
+12V: F1.1, J2.1
/A0: JP2.2 (B), R29.2, TP4.1 (1_1), U7.1 (A0)
/A1: JP3.2 (B), R30.2, TP5.1 (1_1), U7.2 (A1)
/A2: JP4.2 (B), R31.2, TP6.1 (1_1), U7.3 (A2)
/A3: JP5.2 (B), R32.2, TP7.1 (1_1), U7.4 (A3)
/A4: JP6.2 (B), R33.2, TP8.1 (1_1), U7.5 (A4)
/A5: JP7.2 (B), R34.2, TP9.1 (1_1), U7.24 (A5)
/EF_DVDT: C64.1, U12.7 (DVDT)
/EF_EN: R78.2, R79.1, U12.1 (EN/UVLO)
/EF_ILIM: R81.1, U12.9 (ILM)
/EF_OVC: R80.1, U12.2 (OVCSEL)
/HOST_3V3: C69.1, J9.2, R16.1, R17.1, R18.1, R19.1, R82.1, R83.1, R84.1, U13.5 (EN), U13.8 (VCCB)
/HOST_SCL: J9.4, R83.2, U13.7 (SCLB)
/HOST_SDA: J9.3, R82.2, U13.6 (SDAB)
/OE: R23.1, U7.23 (#OE)
/PUMP2_PWM: D6.2 (A), U7.8 (PWM2)
/PUMP3_PWM: D7.2 (A), U7.9 (PWM3)
/PUMP4_PWM: D8.2 (A), U7.10 (PWM4)
/RES: R22.2, TP3.1 (1_1), U5.9 (RES)
/SCL: J1.4, J3.4, J12.4, J17.4, R20.1, U5.3 (SCLK/SCL), U7.26 (SCL), U13.2 (SCLA)
/SDA: J1.3, J3.3, J12.3, J17.3, R15.1, U5.2 (MOSI/SDA), U7.27 (SDA), U13.3 (SDAA)
GND: C1.2, C2.2, C8.2, C9.2, C15.2, C16.2, C23.2, C24.2, C25.2, C26.2, C28.2, C29.2, C30.2, C31.1, C32.2, C33.1, C34.2, C42.1, C43.2, C44.1, C45.2, C46.2, C52.2, C53.2, C54.2, C56.2, C57.2, C59.2, C60.2, C61.2, C63.2, C64.2, C65.2, C66.2, C67.2, C68.2, C69.2, D15.1 (K), D33.1 (K), D34.1 (K), D35.1 (K), D36.2 (A), J1.1, J2.2, J2.SH1 (SHIELD), J2.SH2 (SHIELD__1), J2.SH3 (SHIELD__2), J2.SH4 (SHIELD__3), J3.1, J9.1, J12.1, J17.1, J19.1, Q3.2 (S), Q4.2 (S), Q8.2 (S), Q10.2 (S), R23.2, R24.1, R25.1, R26.1, R29.1, R30.1, R31.1, R32.1, R33.1, R34.1, R37.2, R38.2, R46.1, R51.2, R56.2, R74.1, R76.1, R79.2, R80.2, R81.2, R84.2, R85.2, SW1.3, SW1.4, SW2.3, SW2.4, SW3.3, SW3.4, SW4.3, SW4.4, U1.3 (GND), U2.3 (GND), U3.3 (GND), U5.10 (VSS), U7.14 (GND), U7.25 (EXTCLK), U12.4 (PGTH), U12.8 (GND), U13.4 (GND)
unnamed: F1.2, Q11.2 (D)
unnamed: D6.1 (K), R24.2
unnamed: D7.1 (K), R25.2
unnamed: D8.1 (K), R26.2
unnamed: D11.2 (A), Q3.3 (D), R39.2, U8.2 (-)
unnamed: D12.2 (A), Q4.3 (D), R40.2, U11.2 (-)
unnamed: D13.1 (K), R39.1
unnamed: D14.1 (K), R40.1
unnamed: D15.2 (A), R44.1
unnamed: D16.2 (A), Q8.3 (D), R54.2, U9.2 (-)
unnamed: D17.1 (K), R54.1
unnamed: D18.2 (A), Q10.3 (D), R59.2, U10.2 (-)
unnamed: D19.1 (K), R59.1
unnamed: D33.2 (A), R73.1
unnamed: D34.2 (A), R75.1
unnamed: D35.2 (A), R77.1
unnamed: D37.2 (A), Q11.1 (G), R85.1
unnamed: Q3.1 (G), R35.1, R37.1
unnamed: Q4.1 (G), R38.1, R42.1
unnamed: Q8.1 (G), R36.1, R51.1
unnamed: Q10.1 (G), R55.1, R56.1
unnamed: C3.1, U1.4 (BST)
unnamed: R1.2, U1.5 (EN)
unnamed: C55.2, R45.1, R46.2, U1.6 (FB)
unnamed: C3.2, L1.1, U1.2 (SW)
unnamed: C4.1, U2.4 (BST)
unnamed: R4.2, U2.5 (EN)
unnamed: C58.2, R60.1, R74.2, U2.6 (FB)
unnamed: C4.2, L5.1, U2.2 (SW)
unnamed: C5.1, U3.4 (BST)
unnamed: R7.2, U3.5 (EN)
unnamed: C62.2, R61.1, R76.2, U3.6 (FB)
unnamed: C5.2, L2.1, U3.2 (SW)
unnamed: TP2.1 (1_1), U5.8 (EOC)
unnamed: C27.1, U5.4 (VO+)
unnamed: C27.2, U5.6 (VO-)
PUMP0_PWM: R35.2, U7.6 (PWM0)
PUMP1_IN: C25.1, J19.4, R18.2, SW3.1, SW3.2
PUMP1_PWM: R42.2, U7.7 (PWM1)
PUMP2_IN: C26.1, J19.5, R19.2, SW4.1, SW4.2
VALVE1: R55.2, U7.11 (PWM5)
VALVE1_IN: C23.1, J19.2, R16.2, SW1.1, SW1.2
VALVE2: R36.2, U7.12 (PWM6)
VALVE2_IN: C24.1, J19.3, R17.2, SW2.1, SW2.2
VIN: C1.1, C2.1, C8.1, C9.1, C15.1, C16.1, C67.1, R1.1, R4.1, R7.1, U1.1 (VIN), U2.1 (VIN), U3.1 (VIN), U12.6 (OUT)
VIN_RAW: C65.1, C66.1, D36.1 (K), D37.1 (K), Q11.3 (S), R78.1, U12.5 (IN)

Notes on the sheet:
BUCK 12V - 3V3
BUCK 12V - 6V
Open = 0 / Closed = 1
C : X5R/X7R
3_PERIPHERAL
BUCK 12V - 4V5
1_Power
INPUT PROTECTION — REGULATED 12 V ONLY 13.8 V clamp; ~2 A current limit; ~18 ms soft start Validate startup, hot plug and simultaneous loads.
2_Pump / Valve Drivers
4_Switch Inputs
5_Pressure Sensor
7-bit I²C address: 1 A5 A4 A3 A2 A1 A0 (R/W sent separately)
QWIIC MASTER: J9 TO USB / BATTERY ESP32
J3: LOCAL DEBUG BUS (GND / +3V3 / SDA / SCL); onboard supply. J9: dedicated standard Qwiic master port. J1 / J12 / J17: powered sensors. Multiple boards: external TCA9548A at 0x71; one channel active. Disable PCA9685 ALLCALL after initialization.
LOCAL A: RheoBoard +3V3 and sensor bus HOST B: ESP32-supplied +3V3; regulators never paralleled 100 kHz initial bring-up; cable/module pull-ups share a current budget J1 / J12 / J17 remain powered Qwiic sensor ports J3 = LOCAL DEBUG BUS; no master-power isolation at that header
Fused 12 V input: legacy net name retained for existing copper.
BUTTON GPIO TO ESP32
J19 pin 1: GND; pins 2-5: SW1, SW2, SW3, SW4. Active-low; connect J9 Qwiic cable for HOST_3V3 pull-ups. Suggested ESP32 GPIOs: 32, 33, 25, 26 respectively.
Valve channels 5/6: full ON / full OFF only.

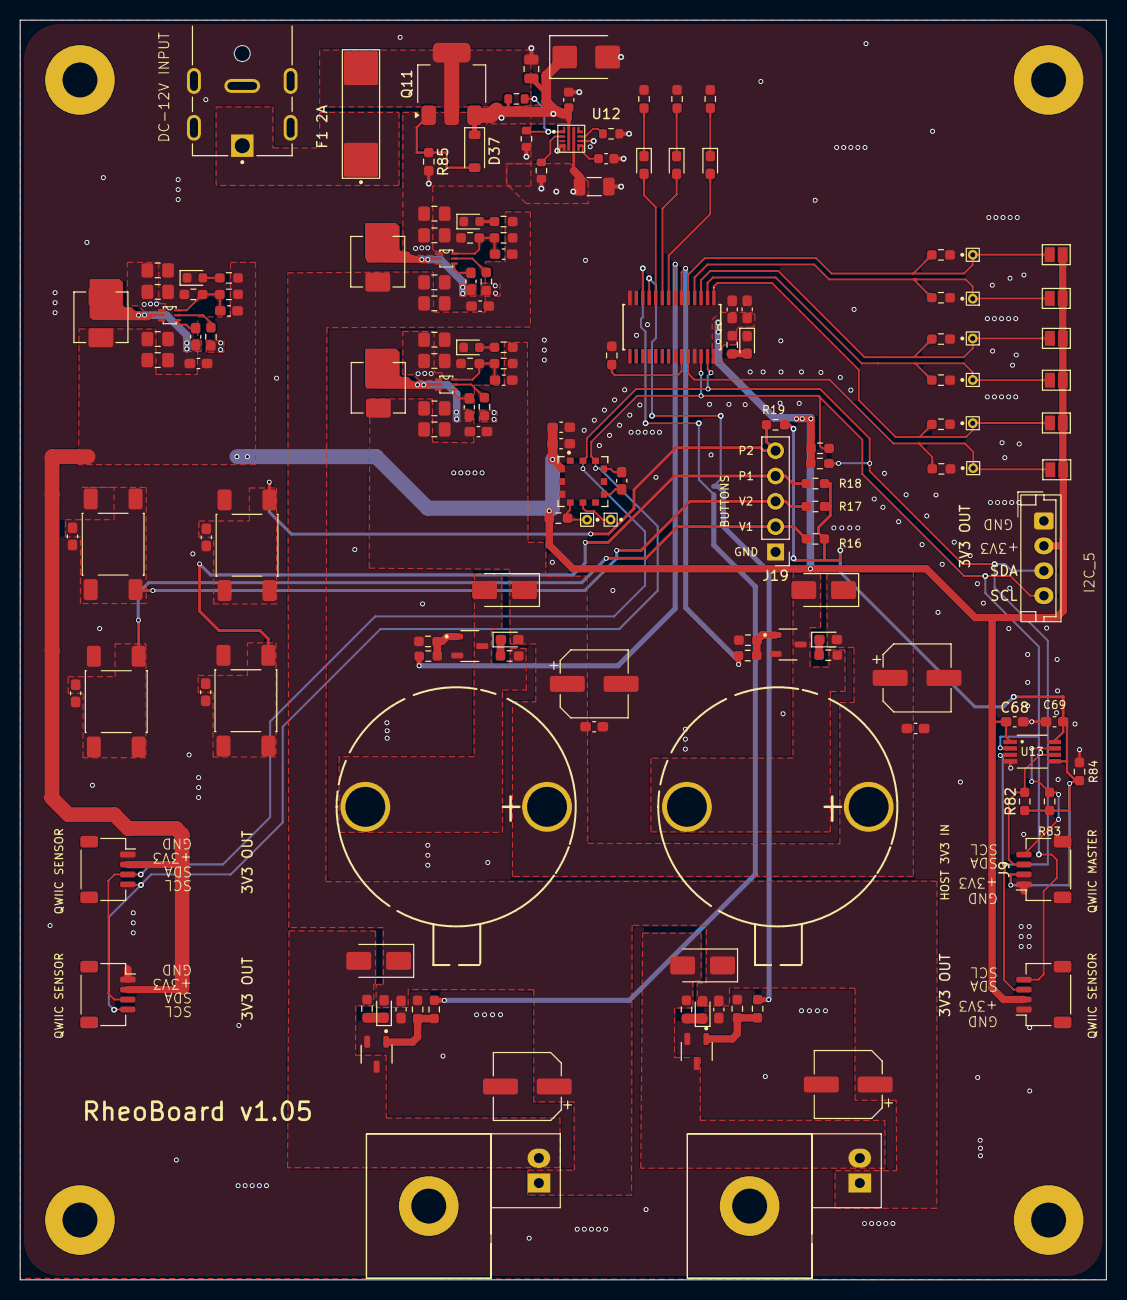
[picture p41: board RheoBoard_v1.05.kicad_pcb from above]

Board: 2 copper layers, 109.0 x 126.4 mm, 160 parts (0 on the bottom side), 71 nets.

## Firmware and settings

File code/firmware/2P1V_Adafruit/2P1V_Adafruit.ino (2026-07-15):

// ============================================================================
// 2P1V_Adafruit -- 2 pumps, 1 valve bench firmware (SparkFun ESP32 Thing Plus +
// L298N), with an Adafruit ATtiny1616 Breakout (seesaw firmware, STEMMA QT /
// Qwiic) between the ESP32 and the two L298N drivers. The ESP32 talks to the
// Button, MicroPressure sensor, and this seesaw board over one shared Qwiic
// (I2C) bus; seesaw pins 0/1 drive L298N #1 ENA/ENB and pin 5 drives L298N #2
// ENB. Pin 4 is reserved for a future VALVE1 channel but physically NC. Unlike
// a plain digital I2C GPIO expander (no PWM), seesaw exposes REAL PWM over
// I2C, so full proportional pump control survives the move off native ESP32
// pins -- RheoSystem's REP phase machine, config percentages, and ramp logic
// are UNCHANGED; only the low-level primitives in PneumaticSystem.h/.cpp
// differ.
// Command namespace is rheo/* (replaces /slip/*).
// One build: BLE pipeline ("2P1V_Adafruit") + USB serial bench stream (SERIAL_STREAM).
// Detailed docs: README.md
//
// SPDX-License-Identifier: MIT
// Copyright (c) 2026 Charlie Vuong -- see ../../../LICENSE
// ============================================================================

// ---- BLE identity (consumed by BLEHandler.h #ifndef guards) -----------------
#define DEVICE_NAME            "2P1V_Adafruit"
#define SERVICE_UUID           "71c978dc-2d05-4a35-b56f-12f4fee4ee31"
#define CHARACTERISTIC_UUID_RX "43d4940a-3037-4040-9c3d-6ecd138325ca"
#define CHARACTERISTIC_UUID_TX "78d88040-6306-40bd-b47d-e1feb75d6482"

// ---- Board ------------------------------------------------------------------
#define BAUDRATE    115200
#define LED_PIN     13
#define BUTTON_PIN  0
#define BTN_DEBOUNCE_MS     25
#define BTN_DOUBLE_CLICK_MS 400
#define BTN_LONG_PRESS_MS   600

#include <Arduino.h>
#include "MemoryStream.h"      // ThingPlusBLEOSC library
#include "BLEHandler.h"        //   -> BLE globals + callbacks; calls routeOSC()
#include "OSCHandler.h"        //   -> OSCMessage, sendSimpleOSC(), sendSampleOSC()
#include <SparkFun_Qwiic_Button.h>
#include "PneumaticSystem.h"   // HAL + PneumaticSystem (pump/valve/sensing)
#include "RheoSystem.h"        // RheoSystem rheo (extends PneumaticSystem)

// ============================================================================
// Globals
// ============================================================================
QwiicButton   qwiicButton;
bool          qwiicButtonReady = false;
char          buffer[255];

// ============================================================================
// OSC router -- incoming server commands over BLE RX
// ============================================================================
void routeOSC(OSCMessage &msg) {
  msg.getAddress(buffer, 0, 255);
  Serial.println(buffer);

  if (rheo.routeOSC(msg, buffer)) return;

  else { Serial.println("Unrecognized OSC address."); }
}

// ============================================================================
// Qwiic button: non-blocking click-pattern state machine
// 1-click = REP, 2-click = toggle latched SUCK, hold = momentary BLOW
// ============================================================================
void handleQwiicButton() {
  if (!qwiicButtonReady) return;
  static bool          pressed       = false;
  static unsigned long pressStartMs  = 0;
  static bool          holdConsumed  = false;
  static int           clickCount    = 0;
  static unsigned long lastReleaseMs = 0;
  static unsigned long lastEdgeMs    = 0;

  unsigned long now     = millis();
  bool          rawDown = qwiicButton.isPressed();

  if (rawDown != pressed && (now - lastEdgeMs) >= BTN_DEBOUNCE_MS) {
    lastEdgeMs = now;
    if (rawDown) {
      pressed = true; pressStartMs = now; holdConsumed = false;
    } else {
      pressed = false;
      if (holdConsumed) { if (rheo.manualBlowing) rheo.stopBlow(); }
      else              { clickCount++; lastReleaseMs = now; }
    }
  }

  if (pressed && !holdConsumed &&
      (now - pressStartMs) >= BTN_LONG_PRESS_MS && !rheo.manualBlowing && !rheo.recording) {
    rheo.blow();
    holdConsumed = true;
  }

  if (clickCount > 0 && !pressed && (now - lastReleaseMs) > BTN_DOUBLE_CLICK_MS) {
    if (!rheo.recording) {
      if (clickCount == 1) rheo.startRep();
      else                 rheo.toggleSuck();
    }
    clickCount = 0;
  }
}

// ============================================================================
// Serial commands (bench-only): REP / STOP / PUMP1 <pct> / PUMP2 <pct>
// ============================================================================
#if SERIAL_STREAM
void handleSerialCommand() {
  static char    cmd[16];
  static uint8_t n = 0;
  while (Serial.available()) {
    char c = Serial.read();
    if (c == '\n' || c == '\r') {
      cmd[n] = '\0'; n = 0;
      if      (!strcmp(cmd, "REP"))        { if (!rheo.recording && !rheo.manualBlowing) rheo.startRep(); }
      else if (!strcmp(cmd, "STOP"))       { if (rheo.recording) rheo.stopRep(); if (rheo.testStreaming) rheo.stopPumpTest(); }
      else if (!strncmp(cmd, "PUMP1 ", 6)) rheo.startPumpTest(PUMP_1, atoi(cmd + 6));
      else if (!strncmp(cmd, "PUMP2 ", 6)) rheo.startPumpTest(PUMP_2, atoi(cmd + 6));
    } else if (n < sizeof(cmd) - 1) {
      cmd[n++] = c;
    }
  }
}
#else
inline void handleSerialCommand() {}
#endif

// ============================================================================
void setup() {
  Serial.begin(BAUDRATE);
  pinMode(LED_PIN, OUTPUT);
  pinMode(BUTTON_PIN, INPUT_PULLUP);

  rheo.setup();
  qwiicButtonReady = qwiicButton.begin();
  Serial.println(qwiicButtonReady ? "Qwiic button ready (1-click=REP, 2-click=suck, hold=blow)."
                                  : "Qwiic button not found (required for documented button controls; continuing without it).");
  // Pass all four explicitly -- setupBLE()'s defaults only resolve per-translation-unit,
  // so an unparameterized call would silently build against BLEHandler.h's placeholder
  // fallbacks (see BLEHandler.h) instead of this sketch's real name/UUIDs.
  setupBLE(DEVICE_NAME, SERVICE_UUID, CHARACTERISTIC_UUID_RX, CHARACTERISTIC_UUID_TX);
  Serial.println("2P1V_Adafruit initialized. Send rheo/api for supported commands.");
}

void loop() {
  static bool buttonPressed = false;

  bool sw1 = sw1Pressed();
  if ((digitalRead(BUTTON_PIN) == LOW || sw1) && !buttonPressed) {
    buttonPressed = true;
    if (rheo.recording) rheo.stopRep(); else rheo.startRep();
    return;
  }
  if (digitalRead(BUTTON_PIN) == HIGH && !sw1) buttonPressed = false;

  handleSerialCommand();
  handleQwiicButton();
  rheo.loop();

  bool active = rheo.recording || rheo.manualBlowing || rheo.latchedSuck || rheo.testStreaming;
  digitalWrite(LED_PIN, active ? HIGH : LOW);
  ledExt(active);

  if (!deviceConnected && oldDeviceConnected) {
    delay(500); pServer->startAdvertising();
    Serial.println("Started advertising again");
    oldDeviceConnected = deviceConnected;
  }
  if (deviceConnected && !oldDeviceConnected) oldDeviceConnected = deviceConnected;
}

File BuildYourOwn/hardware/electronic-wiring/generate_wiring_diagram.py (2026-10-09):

#!/usr/bin/env python3
"""Render the electrical wiring diagram for this design.

SPDX-License-Identifier: CERN-OHL-W-2.0
Copyright (c) 2026 Charlie Vuong -- see ../../../LICENSE

An Adafruit ATtiny1616 Breakout (seesaw firmware, STEMMA QT / Qwiic) sits between the ESP32
Thing Plus and the two L298N drivers. The ESP32's single Qwiic (I2C) bus daisy-chains to three
boards (Button, MicroPressure, seesaw board); the seesaw board's GPIO/PWM pins then drive the
three connected L298N signals that earlier direct-GPIO builds wired straight to the ESP32
(pins 32/33/14). Pin 4 is reserved for a future VALVE1 channel but physically NC. Unlike a
plain digital I2C GPIO expander (no PWM), seesaw exposes real 8-bit PWM over I2C, so pump
drive stays fully proportional -- see README.md.

This is the editable source for the wiring diagram (OSHWA requires design files in a
"preferred format for making changes", not just a rendered raster export). Regenerate the PNG
with:

    python3 generate_wiring_diagram.py

Wiring facts here must stay in sync with:
  - README.md (this folder) -- prose description of the same connections
  - ../../../code/firmware/2P1V_Adafruit/PneumaticSystem.h -- seesaw pin #defines (source of truth)

If you change a connection, update all three together.
"""

import matplotlib
matplotlib.use("Agg")
import matplotlib.pyplot as plt
from matplotlib.patches import FancyBboxPatch

I2C = "#8e44ad"        # Qwiic/I2C bus wiring (purple)
CTRL = "#e07b00"       # seesaw board -> L298N control lines (orange, PWM-capable)
PNEUM = "#3aa0ff"      # L298N -> actuator power leads (blue)
POWER = "#c58b00"      # external +12 V motor supply
GND = "#333333"        # common ground
ESP_C, ESP_E = "#dbeafe", "#1565c0"     # ESP32 Thing Plus
QW_C, QW_E = "#f3e8ff", "#6a1b9a"       # Qwiic peripherals (Button/MPRLS)
SS_C, SS_E = "#fff3cd", "#b8860b"       # ATtiny1616 seesaw board
L298_C, L298_E = "#d8f0d8", "#2e7d32"   # L298N drivers
ACT_C, ACT_E = "#ffe6c2", "#e07b00"     # pumps/valve (actuators)
UNUSED_C, UNUSED_E = "#f0f0f0", "#aaaaaa"  # unused/wired-but-idle
TABLE_C, TABLE_E = "#eef2ff", "#4338ca"    # pin-map reference table

fig, ax = plt.subplots(figsize=(14.5, 10))
ax.set_xlim(0, 116)
ax.set_ylim(0, 100)
ax.axis("off")


def box(x, y, w, h, fc, ec, title, sub="", tsize=10, ssize=7.8, dashed=False):
    ax.add_patch(
        FancyBboxPatch(
            (x, y), w, h, boxstyle="round,pad=0.4,rounding_size=2",
            linewidth=1.6, edgecolor=ec, facecolor=fc, zorder=3,
            linestyle="dashed" if dashed else "solid",
        )
    )
    ax.text(x + w / 2, y + h - h * 0.28, title, ha="center", va="top",
             fontsize=tsize, fontweight="bold", color=ec, zorder=4)
    if sub:
        ax.text(x + w / 2, y + h * 0.32, sub, ha="center", va="center",
                 fontsize=ssize, color="#333333", zorder=4, linespacing=1.5)


def l298_box(x, y, w, title, motor_a_rows, motor_b_rows):
    """Draw one L298N module with every screw/header terminal accounted for."""
    h = 22
    ax.add_patch(
        FancyBboxPatch(
            (x, y), w, h, boxstyle="round,pad=0.4,rounding_size=2",
            linewidth=1.6, edgecolor=L298_E, facecolor=L298_C, zorder=3,
        )
    )
    ax.text(x + w / 2, y + h - 1.2, title, ha="center", va="top",
            fontsize=9.5, fontweight="bold", color=L298_E, zorder=4)
    ax.text(x + w / 2, y + h - 3.5, "5V-EN jumper ON  \u00b7  ENA/ENB jumper caps OFF",
            ha="center", va="top", fontsize=6.4, fontweight="bold",
            color=L298_E, zorder=4)
    ax.text(x + w * 0.25, y + h - 5.2, "MOTOR A", ha="center", va="top",
            fontsize=6.8, fontweight="bold", color="#555555", zorder=4)
    ax.text(x + w * 0.75, y + h - 5.2, "MOTOR B", ha="center", va="top",
            fontsize=6.8, fontweight="bold", color="#555555", zorder=4)
    ax.plot([x + w / 2, x + w / 2], [y + 5.2, y + h - 5.2],
            color="#92b892", lw=0.8, zorder=4)
    for i, (motor_a, motor_b) in enumerate(zip(motor_a_rows, motor_b_rows)):
        row_y = y + h - 7.3 - i * 2.15
        ax.text(x + 1.2, row_y, motor_a, ha="left", va="top",
                fontsize=6.1, color="#222222", fontfamily="monospace", zorder=4)
        ax.text(x + w / 2 + 1.0, row_y, motor_b, ha="left", va="top",
                fontsize=6.1, color="#222222", fontfamily="monospace", zorder=4)
    ax.plot([x + 1.2, x + w - 1.2], [y + 4.6, y + 4.6],
            color="#92b892", lw=0.8, zorder=4)
    ax.text(x + w / 2, y + 2.35,
            "12V: external in  \u00b7  +5V: local regulator output  \u00b7  GND: common",
            ha="center", va="center", fontsize=6.1, color="#222222",
            fontfamily="monospace", zorder=4)


def wire(pts, color, lw=3.0, dashed=False):
    xs = [p[0] for p in pts]
    ys = [p[1] for p in pts]
    ax.plot(xs, ys, color=color, lw=lw, solid_capstyle="round",
             solid_joinstyle="round", zorder=2,
             linestyle="dashed" if dashed else "solid")


def node(x, y, color):
    ax.plot([x], [y], marker="o", ms=7, mfc=color, mec="white", mew=1.1, zorder=5)


def ground_symbol(x, y_top, scale=1.0):
    """Draw the standard three-bar ground symbol below a connection point."""
    y_bar = y_top - 2.0 * scale
    ax.plot([x, x], [y_top, y_bar], color=GND, lw=2.2,
            solid_capstyle="round", zorder=2)
    for offset, width in ((0.0, 3.2), (0.75, 2.1), (1.5, 1.0)):
        y = y_bar - offset * scale
        half_width = width * scale / 2
        ax.plot([x - half_width, x + half_width], [y, y], color=GND, lw=2.2,
                solid_capstyle="round", zorder=2)


# ---- Title ------------------------------------------------------------ #
ax.text(58, 99, "RheoBoard DIY — Electrical Schematic",
         ha="center", va="top", fontsize=14.5, fontweight="bold")

# Keep the design summary and every legend label inside one box. The source
# diagram placed the summary just above a shorter legend box, which allowed the
# text to overlap the border in tightly cropped/rendered previews.
ax.add_patch(FancyBboxPatch((3, 89.8), 110, 6.2,
                             boxstyle="round,pad=0.3,rounding_size=1.5",
                             linewidth=1.0, edgecolor="#999999", facecolor="#f6f6f6", zorder=1))
ax.text(58, 94.4,
        "ESP32 Thing Plus + Adafruit ATtiny1616 (seesaw) + 2\u00d7 L298N  \u00b7  "
        "seesaw pins 0/1/5 replace ESP32 GPIO 32/33/14; pin 4 reserved/NC  \u00b7  real PWM preserved",
        ha="center", va="center", fontsize=8.2, color="#555555")
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

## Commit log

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2026-07-07 Set up harness engineering scaffolding for solo, direct-to-main dev
    Adapts the practices from Anthropic's long-running-agent harness posts and
    OpenAI's harness engineering post to a solo hardware developer working
    directly on main (no branches/PRs):
    - AGENTS.md: short repo map with session bootstrap/wrap-up checklist and
    the solo working agreement (commit directly to main, git log + progress
    notes as the continuity mechanism across sessions).
    - docs/ as the system of record: design-docs (operating principles),
    exec-plans (active/completed/tech-debt-tracker/template), product-specs,
    references, and hardware-specific docs (BOM tracking, revision history,
    verification checklist) to c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
2026-07-07 Build out Instructables-style tutorial structure for BYO track
    Replaces the flat BuildYourOwn/ASSEMBLY.md with a proper step-by-step build
    guide, plus the supporting design-file categories requested:
    - BuildYourOwn/laser-cut/: scaffold + conventions for the laser-cut platform
    design files (vector source of truth, DXF for cutting, material/thickness/
    kerf notes).
    - BuildYourOwn/wiring/: updated to recommend pictographic/breadboard-style
    circuit diagrams (e.g. Fritzing) over pure schematics.
    - BuildYourOwn/tutorial/: Instructables-style guide with a README
    table-of-contents/intro, one numbered folder per step under steps/ (each
    with its own README + media/), and a _step-template/ to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
2026-07-07 Remove redundant docs/hardware/build-your-own/, consolidate into BuildYourOwn/
    docs/ and BuildYourOwn/ had drifted into overlapping structures. Fixed:
    - docs/hardware/build-your-own/bom.md was pure indirection (pointer + notes
    about BuildYourOwn/BOM.md) -- merged its notes directly into BOM.md.
    - docs/hardware/build-your-own/revision-history.md duplicated
    docs/PROGRESS.md/git log with no added value, since BuildYourOwn/ is plain
    markdown and already diffs natively (unlike the PCB track's binaries,
    which genuinely need an external revision log). Deleted, not replaced.
    - docs/hardware/build-your-own/verification-checklist.md had real unique
    content but was misplaced under docs/ -- m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
2026-07-07 Close the "agent can't verify physical work" gap in the harness
    Re-audited against the three source articles (Anthropic long-running-agent
    posts, OpenAI harness engineering post) for gaps, not just structure.
    The core issue: every harness in those articles relies on the agent being
    able to run the software itself (Playwright, curl) to catch premature "done"
    claims. This agent can't solder, cut, or wire anything, so that guard rail
    was completely missing for physical work. Fixes:
    - AGENTS.md: new "What the agent can and can't verify" section drawing a
    hard line between agent-executable (docs/BOM/tutorial writing) and
    human-only (anything physical) work, with an explicit rule against
    c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
2026-07-07 Consolidate docs/ entirely into BuildYourOwn/
    docs/ and BuildYourOwn/ kept reading as duplicate structures even after the
    last cleanup pass. The actual fix: stop having two top-level trees. BYO is
    the only active track, and everything under docs/ that wasn't PCB-specific
    was really about BYO anyway.
    - Moved into BuildYourOwn/ (flat): PROGRESS.md, core-beliefs.md,
    product-specs.md, references.md, exec-plans/ (active/completed/
    tech-debt-tracker/template). Dropped design-docs/index.md's wrapper --
    it only ever pointed at one file.
    - Deleted docs/hardware/pcb/ (BOM notes, revision history, verification
    checklist for the Altium track) rather than relocating it. That track is
    dormant;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
2026-07-08 Update documentation and refine product specifications for RheoMap, RheoData, and SlipAtlas
    - Revised AGENTS.md and README.md to reflect updated product names and clarify the focus on RheoMap, RheoData, and SlipAtlas.
    - Enhanced the BOM.md with detailed parts list for the 2P1V rig, including links to datasheets and specific product details.
    - Updated product-specs.md to include new specifications for RheoData and SlipAtlas.
    - Improved wiring documentation with clear diagrams and summaries for the 2P1V rig setup.
    - Restructured tutorial and references to align with the new documentation model inspired by Calico and OpenTheremin V4.
    These changes aim to provide clearer guidance for builders a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
    [PneumaticSystem.cpp, PneumaticSystem.h, RheoSystem.cpp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]
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2026-07-08 Refactor documentation to remove "2P1V" branding and update references
    - Renamed `software/2P1VX/` to `software/rheometer-firmware/` while keeping internal files unchanged, as per user request to avoid altering firmware or code.
    - Updated documentation across multiple files (`BOM.md`, `README.md`, `PROGRESS.md`, etc.) to replace "2P1V" and "2P1VX" with generic terms like "this design" and "this simple rheometer."
    - Ensured all path references were updated accordingly, maintaining clarity and consistency throughout the documentation.
    - Added a new user-provided image of the assembled bench build to `README.md` and updated related image documentation.
    These changes aim to enhance the user exp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
    [PneumaticSystem.cpp, PneumaticSystem.h, RheoSystem.cpp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]
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2026-07-08 Replace all instances of "BYO" with "DIY" across documentation for consistency and clarity. Updated relevant files including `AGENTS.md`, `BOM.md`, `README.md`, and various tutorial steps. Regenerate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
2026-07-08 Enhance licensing clarity and documentation for OSHWA certification readiness
    - Added a comprehensive licensing section in `AGENTS.md`, detailing the three separate licenses for hardware, firmware, and documentation.
    - Updated `README.md` to reflect the new licensing structure and clarified the project's OSHWA certification status.
    - Documented the licensing details in `BuildYourOwn/README.md`, `BOM.md`, and `wiring/README.md` to ensure consistency across all relevant files.
    - Introduced a checklist for OSHWA self-certification readiness in `VERIFICATION.md`, outlining the necessary steps and current status.
    - Regenerated the wiring diagram and updated firmware files to include SPDX license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
    [panel.dxf]
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2026-07-14 Migrate Altium project from V8 to V9
    Replaces the legacy RheoBoard_V8 design files with a new RheoBoard_V9 project, including updated PCB, project structure, BOM outputs, and annotation files. The schematic was split into separate functional sheets (COVER/MCU/PERIPHERAL/POWER), output jobs were refreshed, and new vendor libraries/footprints plus a TPS563203 transient PSpice model were added to support the revised design.
    [AO3400A.PcbLib, AP2112K-3P3TRG1.PcbLib, BLM18KG331WH1D.PcbLib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]
2026-07-15 Update V9 POWER schematic document
    Applies schematic edits to `RheoBoard-PCB_V9/POWER.SchDoc` (Altium binary). This commit captures the latest power-sheet design changes in the V9 PCB project.
    [POWER.SchDoc]
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2026-07-15 Update documentation and design files for Rev B integration
    - Revised `okh-RheoBoard.yml` to clarify the status of the Rev B design, including the addition of a placement slot for the ATtiny1616 seesaw breakout.
    - Updated `README.md` to reflect the new status of the laser-cut panel, including the integration of the seesaw breakout and its placement details.
    - Enhanced `PROGRESS.md` with detailed notes on the Rev B updates, including geometry adjustments and documentation synchronization.
    - Adjusted the BOM to include the updated zip-tie count for the seesaw breakout and clarified its placement.
    - Regenerated design files (`panel.svg`, `panel.dxf`, `panel-cut-lines.png`, and `panel-placement-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
    [panel.dxf]
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2026-07-15 Refactor Build Your Own documentation to streamline the builder guide
    - Shortened the builder guide from eight steps to five concise stages, enhancing clarity and usability.
    - Updated all relevant documentation references, including `AGENTS.md`, `okh-RheoBoard.yml`, and various `README.md` files, to reflect the new five-step structure.
    - Revised step descriptions to improve navigation and understanding for builders.
    - Ensured consistency across all documentation related to the build process.
    These changes improve the overall coherence and accessibility of the documentation for users.
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2026-07-17 Update RheoBoard V9 BOM spreadsheet
    Refreshes `RheoBoard_V9.xlsx` with the latest bill of materials revisions for the V9 PCB.
    [RheoBoard_V9.xlsx]
2026-07-18 Update documentation and design files for Rev C
    - Enhanced `.gitignore` to exclude unpublished design variants located in `.private/laser-cut-qmd/`.
    - Updated `okh-RheoBoard.yml` to reflect the new Rev C status, changing `made` to false and revising the version and build notes.
    - Revised `README.md` to clarify that Rev C requires a new physical test-fit due to significant layout changes.
    - Documented detailed changes in `PROGRESS.md`, including the new component arrangement and updated physical envelopes for parts.
    - Adjusted laser-cut panel files (`panel.svg`, `panel.dxf`, and related documentation) to reflect the new dimensions and layout for Rev C.
    These updates ensure accurate represent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
    [panel.dxf, sensing_tube.stl]
2026-07-27 Update documentation and design files for sensing system
    - Revised `okh-RheoBoard.yml` to include new CAD files for the sensing tube and small connector, reflecting their addition to the design files.
    - Documented the sensing-system CAD models in `PROGRESS.md`, detailing the purpose and fit requirements of the new STL files.
    - Updated `BuildYourOwn/README.md` to link to the new CAD folder, ensuring users are aware of the available design resources.
    These changes enhance the documentation and provide clearer guidance for builders regarding the new components.
    [connector_big.stl, connector_small.stl, sensing_tube.scad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]
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2026-09-28 Update BOM and documentation for RheoBoard V1
    - Added Mouser product links for various components in `BOM_RheoboardV1.xlsx`, including resistors, capacitors, and connectors, ensuring accurate sourcing.
    - Documented the updates in `PROGRESS.md`, detailing the linked parts and next steps for user review.
    - Removed outdated 3D models and STEP files from the `RheoboardV1` directory to streamline the project files.
    These changes enhance the BOM accuracy and improve the overall organization of design resources.
    [1-B_Cu.gbr, 1-B_Mask.gbr, 1-B_Paste.gbr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]
2026-09-28 Refine .gitignore to clarify unpublished content
    - Updated the .gitignore file to include a broader exclusion for author/agent working notes and application drafts by replacing the specific path `.private/laser-cut-qmd/` with a general entry for `.private/`.
    - This change enhances the clarity of the repository by ensuring that all unpublished content is consistently ignored.
    These modifications contribute to a cleaner project structure and prevent accidental publication of sensitive or incomplete files.
2026-09-28 Remove obsolete CAD files and update .gitignore
    - Deleted several outdated CAD files, including `connector_big.stl`, `connector_small.stl`, `README.md`, `sensing_tube_open.stl`, `sensing_tube.scad`, and `sensing_tube.stl`, to streamline the projec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
    - Updated the `.gitignore` file to include `AGENTS.md`, ensuring that sensitive documentation remains unpublished.
    These changes contribute to a cleaner and more organized project structure, enhancing maintainability and clarity.
    [connector_big.stl, connector_small.stl, sensing_tube.scad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]
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2026-09-28 Remove obsolete firmware and documentation files for 2P1V_Adafruit
    - Deleted the `README.md`, `2P1V_Adafruit.ino`, `PneumaticSystem.cpp`, `PneumaticSystem.h`, `RheoSystem.cpp`, and `RheoSystem.h` files, which are no longer needed for the project. This cleanup streamlines the repository and eliminates outdated content, contributing to a more organized project structure.
    [2P1V_Adafruit.ino, PneumaticSystem.cpp, PneumaticSystem.h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]
2026-09-28 Remove obsolete BOM file for RheoBoard V1
    - Deleted the `BOM_RheoboardV1.xlsx` file, which is no longer needed for the project. This cleanup contributes to a more organized project structure by eliminating outdated resources.
    [BOM_RheoboardV1.xlsx]
2026-09-28 Update BOM_RheoboardV1.xlsx to reflect recent changes
    - Modified the `BOM_RheoboardV1.xlsx` file to incorporate updated component information and ensure accuracy in sourcing. This change enhances the project's documentation and maintains the relevance o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
    [BOM_RheoboardV1.xlsx]
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2026-09-28 Remove obsolete BOM and CPL files for RheoBoard V1
    - Deleted the `BOM_RheoboardV1.xlsx` and `1-all-pos.csv` files, which are no longer needed for the project. This cleanup contributes to a more organized project structure by eliminating outdated resources.
    [BOM_RheoboardV1.xlsx, BOM_RheoboardV1_JLCSMT.xlsx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]
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2026-10-09 Update documentation and file paths for firmware and software
    - Revised `LICENSE` to correct the path for firmware licensing from `BuildYourOwn/software/` to `firmware/`.
    - Updated `okh-RheoBoard.yml` to reflect the new paths for firmware and software, ensuring consistency across documentation.
    - Enhanced `README.md` to clarify the relationship between firmware and software for the DIY build, PCB, and portable version.
    - Adjusted references in `BuildYourOwn/README.md` and other files to align with the updated structure and improve clarity.
    These changes enhance the accuracy of project documentation and provide clearer guidance for users and contributors.
    [2P1V_Adafruit.ino, PneumaticSystem.cpp, PneumaticSystem.h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]
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2026-10-09 Update documentation and file paths for RheoBoard
    - Revised `LICENSE` to correct the path for firmware licensing from `firmware/` to `code/firmware/`.
    - Updated `okh-RheoBoard.yml` to reflect new paths for firmware and software, ensuring consistency across documentation.
    - Enhanced `README.md` and `BuildYourOwn/README.md` to clarify the relationship between firmware, software, and the DIY build, PCB, and portable version.
    - Adjusted references in various documentation files to align with the updated structure and improve clarity.
    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
    [BOM_RheoboardV1_JLCSMT.xlsx]
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2026-10-10 Remove redundant J18 header and update documentation for RheoBoard v1.05
    - Removed the J18 local service header from the PCB design, as it is no longer needed.
    - Updated the assembly instructions to reflect the removal of J18 and clarified the role of J3 as the local debug header.
    - Revised the README and BOM to indicate the changes in the connector layout and part count.
    - Adjusted the Gerber files and other manufacturing documents to ensure consistency with the updated design.
    These changes streamline the design and improve the clarity of the documentation for users and manufacturers.
    [1-B_Cu.gbl, 1-B_Mask.gbs, 1-B_Paste.gbp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]
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2026-10-10 Update file paths and remove obsolete images for RheoBoard documentation
    - Corrected paths for OSHW certification mark files in `LICENSE`, `README.md`, and `certification.md` to reflect the new directory structure.
    - Updated references to the JLCPCB top placement image in various documentation files, ensuring consistency with the new file locations.
    - Deleted outdated images and associated README files from the `interpretation` and `img` directories to streamline the project.
    These changes enhance the organization and clarity of the RheoBoard project documentation.
    [POWER.kicad_sch, RheoBoard_Altium_Reimport.kicad_pcb, RheoBoard_Altium_Reimport.kicad_sch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]
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2026-10-10 Update RheoBoard v1.05 design files and documentation
    - Revised the assembly and bringup instructions to clarify the inspection process for components, including the new Q11 MOSFET and D37 zener diode.
    - Updated the revision notes to reflect the acceptance of prototype risks related to U5's reset strategy and valve voltage margins.
    - Enhanced the BOM to include the new reverse-polarity stage components and updated part counts.
    - Adjusted manufacturing files to ensure consistency with the latest design changes, including the removal of obsolete Gerber files.
    These changes improve the clarity, usability, and accuracy of the RheoBoard project files and documentation.
    [BOM_RheoBoard_v1.05.xlsx, BOM_RheoBoard_v1.05_JLCPCB.csv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]
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2026-10-11 Replace the assembly drawing with the closer lid-off view.
    The extra white margin is cropped so the box fills the picture.
2026-10-12 Update pneumatic wiring documentation and clarify assembly instructions
    - Revised the pneumatic port table to specify the sensing tube instead of the chamber/nozzle.
    - Added detailed labeling instructions for the pneumatic connections.
    - Updated the assembly tools section to clarify the tool list reference.
    - Revised calibration and measurement section to distinguish between reading pressure and calibration.
    - Adjusted power-on checks to reflect the correct step title and clarify the testing process.
    These changes aim to enhance clarity and usability of the documentation for users assembling the RheoBoardOTS.
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2026-10-12 Remove aspirator adapter files and related documentation
    - Deleted the aspirator adapter source file, notes, and preview image to streamline the repository.
    - This cleanup ensures that outdated or unverified components are no longer included, maintaining focus on current models and documentation.
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2026-10-12 Replace the DIY electrical wiring diagram with the three-section figure.
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2026-10-19 Replace the RheoBoardOTS plates with the updated one-L298N and two-L298N designs.
    The one-L298N plate is now 190 × 215 × 3 mm, with PWM on the left and the ESP32 on the right.
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2026-10-19 Add the current RheoBoardPipette photo.
    It replaces the packaging concept as the picture of the pipette build.
2026-10-19 Replace the generated pipette picture with the current RheoBoardPipette photo.
    The home figure and the old packaging sheet were still showing that render.
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2026-10-24 Update RheoBoard v1.05 documentation and manufacturing files. Refined assembly and bringup notes to include updated LED polarity and connector specifications. Corrected footprint and layout details b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
2026-10-28 Update BOM and manufacturing files for RheoBoard v1.05. Adjusted component values, added new components, and corrected designator placements. Updated creation timestamps for Gerber and manufacturing 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
2026-10-29 Group sensor reset circuit and refresh schematic images
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2026-10-30 Replace old labeled panel images with current RheoBoardOTS overview
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2026-10-31 Replace panel overview with empty mounting holes
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2026-11-03 Fix datasheet and footprint reference URLs in CAD files
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
